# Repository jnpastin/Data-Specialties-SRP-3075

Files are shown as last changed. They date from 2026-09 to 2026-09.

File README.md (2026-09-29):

# Data Specialties SRP-3075

This repository documents the electrical design of a Data Specialties SRP-3075SD paper tape reader/punch through independently recreated KiCad schematics.

The schematics were produced by reverse engineering an original device. They are not original Data Specialties drawings.

## About the SRP-3075

The Data Specialties SRP-3075 is a tabletop, eight-channel paper tape reader and punch system introduced during the 1970s. It combines an optical tape reader and a tape punch in a single enclosure.

The standard SRP-3075 used separate DTL/TTL-compatible parallel interfaces for the reader and punch. The SRP-3075SD added an RS-232 serial interface for both functions and included data buffering to accommodate the difference between the incoming serial data rate and the mechanical speed of the punch.  The "SD" model designation described in the manual was not present on the sample device, it was designated solely as SRP-3075 or ST1 on the badges affixed to the device.

The serial model supports:

- Paper tape punching at 300, 600, or 750 baud
- Paper tape reading at 300, 600, 750, 1200, 1500, 2400, or 3000 baud
- Eight data channels plus the sprocket channel
- Independent reader and punch control
- RS-232 data and handshake signals
- Remote reader and punch control using ASCII DC1 through DC4 characters
- Buffered punch data while the punch mechanism starts or is temporarily unavailable

The punch operates mechanically at up to 75 characters per second. The optical reader operates at up to 300 characters per second.  This aligns with the available serial baud rates.  Since the serial configuration is 8 data bits and 1 stop bit (8-N-1), each character is 10 bits long.

## Repository Purpose

The purpose of this repository is to preserve the electrical design of the SRP-3075SD and provide usable technical information for:

- Restoration and repair
- Circuit analysis and troubleshooting
- Historical preservation
- Replacement circuit development
- Study of late-1970s paper tape equipment

The available manufacturer technical manual describes installation, operation, interfaces, options, and system-level behavior, but does not contain the complete electrical schematics needed to understand or repair the electronics.

## Repository Contents

Each major assembly directory contains some or all of the following:

- KiCad project files
- Hierarchical KiCad schematics
- Generated netlists
- PDF schematic exports
- Component-location images

The KiCad schematics and netlists are the editable engineering sources. PDF exports are provided for convenient viewing, while component-location images assist with identification and comparison against the physical hardware.  DSI did not silkscreen the boards on the sample unit.  Symbol references are the authors, except where noted in the schematics.

The repository does not currently contain recreated PCB layouts. Any placeholder KiCad PCB files should not be interpreted as representations of the original board routing.

## Source Documentation

The primary manufacturer reference used during this project was:

> Data Specialties Inc., *SP75 / SRP3075 "S" Series Technical Manual*, Specification No. 3601A, July 1978.

A scanned copy is available here and through Bitsavers.

The manual documents the product variants, operating procedures, options, interface signals, timing, and system specifications. It does not include the complete board-level electrical schematics recreated in this repository.

## Reverse-Engineering Method

The schematics in this repository were recreated through examination of original hardware. The work included:

- Identifying components and assemblies
- Tracing printed circuit board connections
- Reconstructing connector pinouts
- Identifying power and signal relationships
- Analyzing circuit operation
- Comparing observed behavior with the manufacturer technical manual
- Creating hierarchical KiCad schematics and netlists

The system is implemented primarily with conventional TTL and CMOS logic, timers, comparators, discrete transistor circuits, and electromechanical drivers. It does not depend on programmable logic, firmware, ROM-based control, or undocumented microcode.

Because the behavior is represented directly by the circuitry, the electrical reverse engineering is considered substantially complete. Corrections may still be made as restoration and functional testing of the original device continue.

---

## System Architecture

The SRP-3075 consists of four major electrical assemblies represented in this repository.

### Serial Interface and Reader Control

The serial and reader-control board provides the external RS-232 interface and controls the optical tape reader.

Its major functions include:

- RS-232 transmit, receive, and handshake interfaces
- Serial-to-parallel conversion for received punch data
- Parallel-to-serial conversion for reader data
- Independent reader and punch baud-rate selection
- Baud-clock generation from a 5.0688 MHz crystal
- Recognition of remote-control characters
- Reader request and stepping control
- Reader data capture and transmission
- Tape-status processing
- Switched 24 V power for the reader motor
- Communication with the main logic and punch-control board

See [Serial Interface and Reader Control](./SRP3075_Serial-Reader_Control/README.md)

### Main Logic and Punch Control

The main logic and punch-control board coordinates punch operation and provides the electrical interface to the punch mechanism, front panel, serial board, motors, sensors, and optional parallel interface.

Its major functions include:

- Punch command and readiness logic
- Received-data buffering
- A 128-character punch FIFO
- Punch data registers
- Punch-cycle sequencing
- Punch-solenoid relay drivers
- Sprocket-punch control
- Punch stepper-motor drive
- AC punch-motor control
- Motor speed detection and synchronization
- Feed control
- Front-panel switch and indicator logic
- Tape-low and tape-error handling
- Power-on reset and system-ready generation
- Interconnection with the serial and reader-control board

See [Main Logic and Punch Control](./SRP3075_Main_Logic-Punch_Control/README.md)

### Optical Tape Reader

The reader assembly is a Decitek 261E7010 optical paper tape reader. It detects the eight data channels and sprocket channel and advances the tape using a stepper-driven transport.

The documented reader electronics include:

- Optical sensing for eight data channels
- Optical sprocket-hole sensing
- Signal conditioning for the optical sensors
- Stepper-motor drive circuitry
- Reader motor and transport connections
- Reader power-supply circuitry
- Interface connections to the serial and reader-control board

See [Decitek Optical Tape Reader](./Decitek_261E7010_Tape_Reader/README.md)

### Power Supply

The power-supply assembly provides the voltage rails used by the logic, serial interface, analog circuitry, motors, and electromechanical drivers.

The documented supply includes:

- +5 V logic supply
- +12 V supply
- -12 V supply
- +24 V control and motor supply
- Rectification, filtering, regulation, and protection
- AC input and transformer connections
- Ground and chassis relationships
- Connections to the other system assemblies

See [Power Supply](./SRP3075_PowerSupply/README.md)

## Data Flow

### Punch Path

Serial data enters through the RS-232 interface on the serial and reader-control board. The serial controller converts each received character into parallel data and passes it to the main logic board.

The main logic board stores the received characters in the punch FIFO. This allows data reception to continue while the punch motor starts and accommodates temporary differences between the serial input rate and the mechanical punch rate.

Characters are transferred from the FIFO into the punch registers and presented to the relay-driver channels. The punch sequencer coordinates the data punches, sprocket punch, tape advance, and mechanical synchronization required for each character.

### Reader Path

The reader-control logic requests a tape step and the reader advances the tape by one character position. The optical reader then presents the eight data-channel states and the sprocket indication to the serial board.

The serial controller loads the reader data and transmits the corresponding serial character through the RS-232 interface. Reader operation is controlled by the front-panel switch, remote-control logic, and the RS-232 Request to Send and Clear to Send signals.

## Remote Control

When remote control is enabled, the serial interface recognizes the ASCII device-control characters DC1 through DC4:

| Character | Function |
|---|---|
| DC1 | Start reader |
| DC2 | Start punch |
| DC3 | Stop reader |
| DC4 | Stop punch |

When remote control is disabled, these characters are handled as ordinary received data and may be punched.

---

## Accuracy and Limitations

The schematics are intended to represent the examined hardware as accurately as possible. Signal names have been assigned or normalized where necessary to make the reconstructed design understandable and maintainable.

Although the reverse engineering is substantially complete, errors remain possible. Restoration, measurement, and functional testing may identify:

- Incorrectly traced connections
- Incorrect component values
- Differences between production revisions
- Undocumented factory modifications
- Repairs or modifications made during the life of the examined device

Any such findings will be incorporated into the schematic set as they are verified.

These materials should not be treated as original manufacturer service documentation. Exercise appropriate care when working with the equipment, particularly around AC line voltage, high-current supplies, motors, and electromechanical assemblies.

## Contributions

Corrections and additional information are welcome, particularly:

- Photographs of other SRP-3075 or SP75 units
- Board-revision information
- Component substitutions
- Original service documentation
- Factory schematic packages
- Verified differences between machine configurations
- Restoration and repair findings

Please include supporting observations, measurements, photographs, or documentation when proposing technical corrections.

## License

This repository is licensed under the terms provided in LICENSE.

Manufacturer names, model numbers, and trademarks are used for identification and historical documentation.

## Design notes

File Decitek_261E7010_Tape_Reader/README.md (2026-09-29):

# Decitek 261E7010 Optical Tape Reader

## Overview

This directory contains reverse-engineered schematics and supporting material for the Decitek 261E7010 optical paper tape reader used in the Data Specialties SRP-3075.

The 261E7010 was a third-party OEM reader module incorporated into the SRP-3075. It provides the optical sensing, signal conditioning, and electromechanical transport needed to read eight-channel, one-inch paper tape.

The schematics were recreated through examination of the reader installed in an original SRP-3075. They are not original Decitek or Data Specialties drawings.

## Function within the SRP-3075

The reader forms the input side of the SRP-3075 reader/punch system. It performs three primary functions:

- Detects the eight data channels and sprocket channel
- Conditions the optical sensor outputs into logic-level signals
- Advances the tape one character position when commanded

The reader connects to the [Serial Interface and Reader Control](../SRP3075_Serial-Reader_Control/README.md), which provides reader sequencing, serial conversion, baud-rate generation, and switching of the reader module’s 24V supply.

The reader module does not perform serial conversion or interpret character values.

## Physical Construction

The reader consists of three main functional sections:

- Optical read station
- Signal-conditioning electronics
- Stepper-driven tape transport

Tape passes through a fixed optical read station containing eight data-channel sensors and one sprocket-channel sensor. A single motor drives the feed mechanism and sprocket through a belt.

The reader is designed as a self-contained OEM module with direction and data-polarity capabilities that are not fully exposed by the SRP-3075.

## Optical Read Station

The read station contains nine optical sensing channels:

- Data Channel 1
- Data Channel 2
- Data Channel 3
- Data Channel 4
- Data Channel 5
- Data Channel 6
- Data Channel 7
- Data Channel 8
- Sprocket Channel

The sensors have been identified as photoresistive devices based on observed behavior. Their exact manufacturer and part numbers have not been identified.

Each sensor changes resistance according to the amount of light passing through its corresponding tape position. The resulting signals are processed by the reader’s analog conditioning circuitry.

The sprocket channel identifies the feed hole associated with each character position. It provides the alignment indication needed to determine when the eight data-channel outputs represent valid character data.

## Signal Conditioning

The photoresistor outputs are converted into logic-level signals by circuitry within the reader assembly.

The signal-conditioning circuitry provides:

- Sensor biasing
- Threshold detection
- Logic-level conversion
- Individual outputs for the eight data channels
- A separate sprocket-channel output

The resulting signals are passed to the Serial Interface and Reader Control board for capture and serial transmission.

## Tape Transport

Tape movement is provided by a single variable-reluctance stepper motor.

The motor drives both the tape-feed mechanism and the sprocket through a belt. The transport advances the tape in discrete character-position increments under the control of the reader electronics.

The reader operates in a read-then-step sequence. Character data is observed while the tape is stationary, after which the transport advances the next character position into alignment with the read station.

## Power and Stepping Control

The reader assembly contains the stepper-motor drive circuitry. The Serial Interface and Reader Control board does not switch individual motor phases directly.

The serial board controls reader operation by switching the +24 V power supplied to the reader module. Its reader timing circuitry also provides the request or stepping control used by the module to advance the tape.

The switched supply is identified as `+24V_SW` in the reconstructed schematics.

## Direction Control

The Decitek reader supports bidirectional tape movement.

A direction-control input selects the direction in which the stepper-drive circuitry advances the transport. This reflects the reader’s design as a general-purpose OEM module rather than a subsystem developed specifically for the SRP-3075.

The SRP-3075 does not expose this capability. The direction input has no signal connected on the Serial Interface and Reader Control board, leveraging the internal pull-up which forces the reader to operate in a single direction.

Direction is therefore not selectable by the operator, the host system, or the SRP-3075 control logic.

## Data Polarity

The reader supports selectable output polarity.

A polarity-control input determines the logical interpretation of a detected hole. The module can represent a hole as either:

- Logical one, or mark
- Logical zero, or space

The SRP-3075 does not expose this selection. The polarity input has no signla connected on the Serial Interface and Reader Control board, relying on the internal pull-up, so that a hole is always reported as a logical one, or mark.

Polarity is therefore not configurable by the operator or host system.

## Interface

The reader connects to the Serial Interface and Reader Control board through a 20-position connector.

The interface includes the following categories of connections:

### Power

- Switched +24 V reader supply
- Reader logic and sensing supplies
- Ground connections

### Control Inputs

- Tape-step or reader-request control
- Direction selection
- Hole-polarity selection

### Sensor Outputs

- Reader Channel 1
- Reader Channel 2
- Reader Channel 3
- Reader Channel 4
- Reader Channel 5
- Reader Channel 6
- Reader Channel 7
- Reader Channel 8
- Reader Sprocket

The direction and polarity inputs are fixed by wiring on the Serial Interface and Reader Control board. They are functional capabilities of the reader module but are not variable during normal SRP-3075 operation.

## Repository Contents

This directory contains:

- KiCad project files
- Hierarchical KiCad schematics
- A generated netlist
- A PDF schematic export
- A component-location image

The KiCad schematics and netlist are the editable engineering sources. The PDF is provided for convenient viewing, and the component-location image assists with locating parts on the original assembly.

The repository does not contain a recreated PCB layout. Any placeholder KiCad PCB file should not be interpreted as representing the original board routing.

## Schematic Organization

The reconstructed design is divided into functional sheets covering:

- Optical sensing and signal conditioning
- Tape-reader motor drive
- Reader power supply and distribution

This organization is intended to make the operation of the circuit easier to understand. It does not necessarily reflect the organization of any original Decitek documentation.

## Reverse-Engineering Notes

The schematics were recreated by identifying components, tracing PCB connections, analyzing circuit operation, and comparing the assembly’s behavior with the available Data Specialties documentation.

The examined board includes complete component reference designators, but Decitek used an unconventional scheme for the integrated circuits. Each IC is identified by a single letter rather than a conventional `U`-prefixed number.

KiCad requires the reference to contain a numeric portion, so `_1` is appended to each original IC designation in the reconstructed schematics. Unit letters then identify individual gates or sections within the device. For example, `F_1B` identifies unit B of the IC marked `F` on the original assembly. The suffix does not imply the existence of an `F_2` device.

The reverse engineering of the assembly is considered substantially complete. No programmable logic, firmware, ROM-based control, or other inaccessible logic is present.

## Accuracy and Open Questions

The schematics are believed to accurately represent the examined assembly. Corrections may still be made as restoration and functional testing continue.

Remaining identification questions include:

- Exact photoresistor manufacturer and part number
- Exact specifications of the optical illumination components
- Differences between Decitek production revisions
- Differences between this module and modules installed in other equipment

No significant functional uncertainties are presently known.

## Safety

The reader contains moving mechanical components and motor-drive circuitry. Disconnect power before servicing the assembly or working near the tape transport.

Exercise care when testing the reader outside the complete SRP-3075 because the module depends on externally supplied power and control connections.

## License

This material is licensed under the [terms provided in the repository](../LICENSE).

Manufacturer names, model numbers, and trademarks are used only for identification and historical documentation.

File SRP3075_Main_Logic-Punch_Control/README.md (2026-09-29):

# SRP-3075 Main Logic and Punch Control

## Overview

This directory contains reverse-engineered schematics and supporting material for the Main Logic and Punch Control board used in the Data Specialties SRP-3075.

The Main Logic and Punch Control board is the central system board of the SRP-3075. It serves as the primary interconnection point for the machine's subsystems and is responsible for system coordination, punch data handling, punch control, front-panel operation, and parallel-interface functions.

The schematics were recreated through examination of an original SRP-3075. They are not original Data Specialties drawings.

## Function within the SRP-3075

Responsibility for machine operation is divided between this board and the Serial Interface and Reader Control board.

The Main Logic and Punch Control board is responsible for:

- System clock generation
- Power-on reset generation
- Front-panel controls and indicators
- Punch data buffering
- Punch sequencing
- Punch motor control
- Punch relay drive
- Punch stepper control
- Parallel-interface support
- System-level coordination
- Interconnection of the machine's assemblies

The Serial Interface and Reader Control board provides serial communications and reader-control functions, while this board provides the core machine-control functions required to operate the punch mechanism.

## System Architecture

The Main Logic and Punch Control board serves as the connectivity hub for the SRP-3075.

Major connections include:

- Serial Interface and Reader Control board
- Punch mechanism
- Front panel
- Power supply
- AC motor sensor
- Stepper motor
- Optional parallel-interface circuitry
- Optional low tape detection module (Option G)

Most machine control signals pass through this board.

## Data Flow

The punch datapath is shown below.

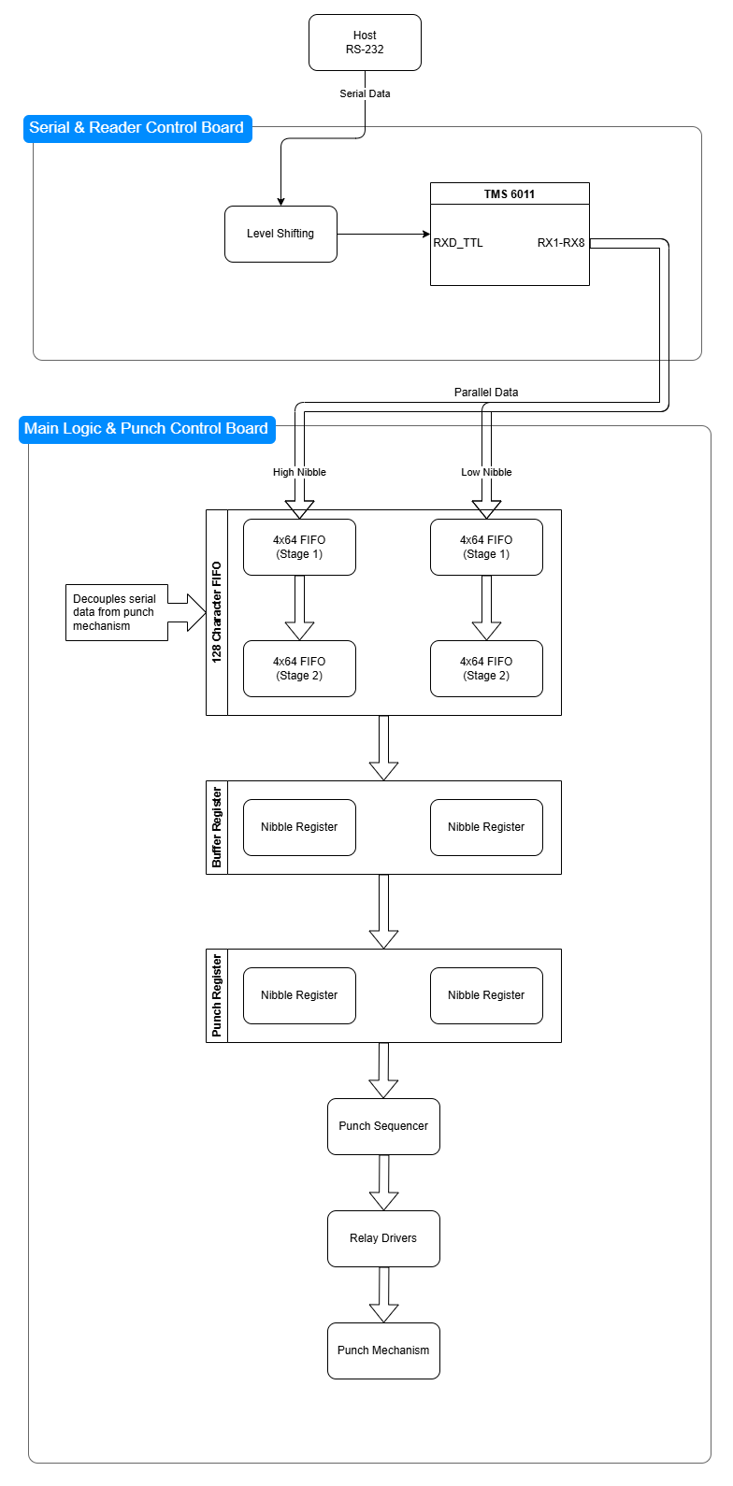
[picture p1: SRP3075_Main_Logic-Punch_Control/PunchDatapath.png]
Punch Datapath Flowchart


A received character passes through several stages before it reaches the punch mechanism:

1. The Serial Interface and Reader Control board converts incoming serial data into parallel character data.
2. The character enters the FIFO buffer.
3. The FIFO transfers the next available character into the Buffer Register.
4. The Buffer Register transfers the character into the Punch Register.
5. The Punch Sequencer coordinates the punch cycle.
6. Relay-driver circuitry energizes the appropriate punch channels.
7. The punch mechanism produces the corresponding tape pattern.

This staged approach allows serial reception, FIFO buffering, punch preparation, and mechanical punching to operate largely independently.

## FIFO Buffer

Received punch data is stored in a 128-character FIFO buffer.

The FIFO is implemented using four 3341 FIFO devices arranged as two cascaded paths:

- High nibble path
- Low nibble path

Each path uses two 64×4 FIFO devices connected in cascade, providing a total storage capacity of 128 punch characters.

The FIFO allows the machine to continue accepting serial data while the punch mechanism is operating or starting.

### FIFO Device Notes

The FIFO implementation uses Signetics 3341 PMOS FIFO memories.

Unlike later TTL memory devices, the 3341 requires:

- +5 V
- GND
- -12 V

This multi-supply requirement was not unusual for memory devices of the period.

Anyone investigating replacements should verify power-supply requirements carefully. Devices with similar functionality may not be electrically compatible even if they appear mechanically compatible.

## Buffer and Punch Registers

Two layers of registers exist between the FIFO and the punch mechanism:

### Buffer Register

The Buffer Register receives the next character from the FIFO and isolates FIFO timing from punch timing.

### Punch Register

The Punch Register contains the character currently being punched.

The punch-control logic operates from the Punch Register outputs rather than directly from FIFO data.

This separation allows the machine to prepare the next character while the current character is being processed.

## System Coordination

Several core machine functions originate on this board.

### System Clock

The main machine timing reference is generated on the Main Logic and Punch Control board and distributed to the remaining circuitry.

### Power-On Reset

The board generates the power-on initialization sequence that establishes a known machine state after power is applied.

### System Ready

Reset and timing circuitry produce the signals that indicate when normal machine operation may begin.

## Punch Control

Punch operation is coordinated by several dedicated subsystems.

### Punch Sequencer

The sequencer controls the order and timing of punch operations.

Responsibilities include:

- Character punching
- Sprocket punching
- Tape advance timing
- Coordination with motor synchronization circuitry

### AC Motor Synchronization

The punch mechanism contains an AC motor with a position sensor.

Synchronization circuitry monitors motor position and derives timing signals used by the punch-control logic.

The design includes:

- Sensor conditioning
- Missing-pulse detection
- Motor-speed monitoring
- Punch timing synchronization

### Stepper Drive

Dedicated circuitry controls tape advancement and punch positioning through the punch stepper subsystem.

### Relay Drivers

Relay-driver circuitry converts logic-level punch data into the power levels required by the punch mechanism.

Individual relay channels correspond to:

- Punch channels 1 through 8
- Sprocket channel (Relay/Punch 9)

## Front Panel Interface

The Main Logic and Punch Control board interfaces directly with the machine's controls and indicators.

Functions include:

- Reader control
- Punch control
- Remote-control enable
- Status indication
- Power indication

This board therefore forms the primary interface between the operator and the machine.

## Parallel-Interface Support

Evidence suggests that the Main Logic and Punch Control board was designed for use across multiple SRP-3075 variants.

The examined board contains populated circuitry associated with a parallel punch interface.

In the serial configuration this functionality is disabled by the `/SERIAL_DETECT` signal supplied by the Serial Interface and Reader Control board.

The corresponding reader-side parallel-interface circuitry is not populated on the examined board. An unpopulated DIP-14 footprint is present in this area.

These observations suggest that Data Specialties likely used a common logic board across multiple SRP-3075 configurations, with variant-specific functionality provided through different companion interface boards and selective component population.

This conclusion is based on observed hardware and should be considered an informed reconstruction rather than documented manufacturer information.

## Connectors

This board acts as the primary interconnection point for the system.

Connectors include:

- Power-supply interface
- Serial-board interface
- Front-panel interface
- Stepper-motor interface
- AC motor sensor interface
- Relay outputs
- Parallel-interface connections

The board distributes power, timing, status, and control signals among the machine's assemblies.

## Component Reference Designators

The original Main Logic and Punch Control board contained no component reference designators.

All component references shown in the reconstructed schematics were assigned during reverse engineering.

These assigned references are used consistently throughout:

- Schematics
- Netlists
- Component-location documentation
- Restoration notes

They are not original manufacturer designations.

## Repository Contents

This directory contains:

- KiCad project files
- Hierarchical KiCad schematics
- Generated netlists
- PDF schematic exports
- Component-location images

The KiCad schematics and netlists are the editable engineering sources.

The repository does not currently contain recreated PCB layouts. Any placeholder PCB files should not be interpreted as representations of the original board routing.

## Reverse-Engineering Notes

The schematics were recreated by:

- Component identification
- PCB tracing
- Connector reconstruction
- Signal tracing
- Functional analysis
- Comparison with available manufacturer documentation
- Cross-reference against the Serial Interface and Reader Control board and Power Supply schematics

Signal names were assigned or normalized where necessary to make the design understandable and maintainable.

The reverse engineering of this assembly is considered substantially complete.

## Accuracy and Open Questions

The schematics are believed to accurately represent the examined hardware.

Corrections may still be incorporated as restoration and functional testing continue.

Areas that may benefit from additional investigation include:

- Differences between production revisions
- Alternative interface-board configurations
- Factory-installed options
- Undocumented hardware modifications
 
No significant functional uncertainties are presently known.
 
## Safety
 
This board contains connections to:
 
- AC motor-control circuitry
- Relay-driver circuitry
- +24 V power circuitry
- External electromechanical assemblies
 
Disconnect power before servicing the machine and verify proper connector placement before reconnecting associated assemblies.
 
## License
 
This material is licensed under the terms provided in the ../LICENSE.
 
Manufacturer names, model numbers, and trademarks are used only for identification and historical documentation.

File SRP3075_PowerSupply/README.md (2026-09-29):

# SRP-3075 Power Supply

## Overview

This directory contains reverse-engineered schematics and supporting material for the power-supply assembly used in the Data Specialties SRP-3075.

The power supply provides the DC rails required by the logic boards, serial interface, optical tape reader, punch-control circuitry, and electromechanical assemblies.

The schematics were recreated through examination of the power supply in an original SRP-3075. They are not original Data Specialties drawings.

## Function within the SRP-3075

The power-supply assembly converts incoming AC power into the DC supplies used throughout the device.

The documented outputs include:

- +5V for digital logic
- +12V for analog and interface circuitry
- -12V for analog and serial-interface circuitry
- +24V for motors, relays, solenoids, and other electromechanical loads
- Logic ground, identified as `GND`
- 24V power return, identified as `GND_24V`

The supply connects primarily to the [Main Logic & Punch Control](../SRP3075_Main_Logic-Punch_Control/README.md) board, which distributes power to the remaining assemblies.

## Power-Supply Architecture

The reconstructed design is divided into three functional sections:

- +5V rail
- +12V and -12V rails
- +24V rail

The positive regulated supplies use external pass transistors to provide additional output-current capability:

- The +5V rail uses one external pass transistor.
- The +12V rail uses one external pass transistor.
- The +24V rail uses two external pass transistors.
- The -12V rail does not use an external pass-transistor stage.

The schematics preserve the distinction between logic ground and the higher-current 24V return where that distinction is present in the original design.

## +5V Rail

The +5V rail supplies the TTL and CMOS logic used throughout the SRP-3075.

The circuit includes:

- Transformer input
- Rectification
- Bulk filtering
- Voltage regulation
- One external pass transistor
- Current-limiting and protection circuitry
- Output filtering

The regulator controls the external pass transistor, which provides the output-current capability required by the machine's digital logic.

## +12V and -12V Rails

The +12V and -12V rails supply analog, timing, sensing, and RS-232 interface circuitry.

These rails are used by circuitry including:

- RS-232 line interfaces
- Operational amplifiers and comparators
- Analog sensing circuits
- Timing and threshold circuits

The +12V rail uses a regulator with one external pass transistor to provide additional output-current capability.

The -12V rail is implemented separately and does not use an external pass-transistor stage.

## +24V Rail

The +24V rail supplies the higher-power electromechanical portions of the machine.

Loads associated with this rail include:

- Punch relay and solenoid drivers
- Punch stepper circuitry
- Reader module power
- Other 24V electromechanical loads

The +24V regulator controls two external pass transistors to provide the required output-current capability.

The design uses a separate return identified as `GND_24V` for the higher-current 24V load path. The relationship between `GND` and `GND_24V` should be preserved when servicing or reconnecting the assembly.  

## Main Logic Board Connector

The power supply connects to the Main Logic and Punch Control board through a multi-position wiring connector.

During reverse engineering, the connector wiring in the examined device was found not to agree with the corresponding connections on the main logic board. The `GND` and `GND_24V` positions were reversed.

This discrepancy was corrected during restoration by repinning the connector.

The connector shown on the root sheet of the reconstructed schematic represents the corrected configuration, not the as-found wiring. A note on the root sheet documents:

- The original as-found discrepancy
- The corrected `GND` and `GND_24V` positions
- The specialized extraction tool required to remove and reposition the connector contacts

Anyone comparing the schematic against an unrestored device should review this note before altering the connector.

Do not assume that another SRP-3075 has already received the same correction. Verify its wiring against the board connections before applying power.

## Grounding

The schematics distinguish among:

- `GND`, used as the logic and low-power circuit reference
- `GND_24V`, used as the return for higher-current 24V loads
- Chassis or protective earth

These connections serve different functions within the reconstructed design and should not be treated as interchangeable connector positions.

`GND` and `GND_24V` are intentionally routed separately throughout the system and are connected together only at the negative terminal of C3 on the power-supply assembly. This single-point connection limits interaction between high-current, high noise 24V return paths and the logic ground system. The connector correction preserves the intended return-current paths for each ground network.

## Component Reference Designators

The original power-supply assembly was only partially annotated. Approximately half of its components carried Data Specialties reference designators, while the remaining components had no visible references.

Original Data Specialties references are preserved unchanged in the reconstructed schematics.

For components without an original reference, an `X` is inserted into the designator to identify the reference as one assigned during reverse engineering.

Examples:

- `C12` is capacitor 12 as designated by Data Specialties.
- `CX7` is the seventh otherwise-unreferenced capacitor assigned during schematic reconstruction.
- `R19` is an original Data Specialties resistor reference.
- `RX7` is an author-assigned reference for an otherwise-unreferenced resistor.

The original and assigned reference sequences are independent. An `X`-marked reference does not imply that a corresponding original reference exists.

This convention preserves the available manufacturer markings while providing every component with a unique identifier for analysis, documentation, and repair.

## Repository Contents

This directory contains:

- KiCad project files
- Hierarchical KiCad schematics
- A generated netlist
- A PDF schematic export
- A component-location image

The KiCad schematics and netlist are the editable engineering sources. The PDF is provided for convenient viewing, and the component-location image assists with locating parts on the physical assembly.

The repository does not contain a recreated PCB layout. Any placeholder KiCad PCB file should not be interpreted as representing the original board routing.

## Schematic Organization

The reconstructed design is divided into functional sheets covering:

- +5V generation and regulation
- +12V generation and regulation
- +24V generation and regulation
- Transformer, AC connections, output connectors, power distribution, and -12V generation and regulation.

The root sheet provides the overall interconnection among the rail circuits, transformer windings, wiring, and output connectors.

Important restoration notes, including the corrected `GND` and `GND_24V` connector positions, are recorded on the root sheet.

## Reverse-Engineering Notes

The schematics were recreated by:

- Identifying components and their values
- Recording available board reference designators
- Assigning references to unmarked components
- Tracing PCB connections
- Tracing chassis and point-to-point wiring
- Reconstructing connector pinouts
- Analyzing regulation and power-distribution circuits
- Comparing power connections against the other SRP-3075 assemblies

Rail and connector names were assigned or normalized where necessary to make the reconstructed design understandable and maintainable.

The reverse engineering of the assembly is considered substantially complete. Corrections may still be made as restoration, measurement, and functional testing continue.

## Accuracy and Restoration Status

The schematics are believed to accurately represent the restored assembly.

The main logic board connector is intentionally drawn in its corrected configuration. It does not reproduce the reversed `GND` and `GND_24V` wiring found during disassembly.

Possible remaining areas for investigation include:

- Differences between production revisions
- Differences among input-voltage configurations
- Undocumented factory changes
- Prior repairs or field modifications
- Exact identification of components whose markings are incomplete

No significant functional uncertainties are presently known.

## Safety

This assembly contains hazardous AC line voltage, high-current DC supplies, large capacitors, and exposed power components.

Before servicing the power supply:

- Disconnect the device from AC power.
- Allow capacitors to discharge.
- Verify stored voltages with appropriate test equipment.
- Confirm the transformer and line-voltage configuration.
- Verify connector wiring before reconnecting any assembly.
- Observe correct polarity when replacing polarized capacitors.
- Preserve protective-earth and chassis connections.

The +24V supply can deliver sufficient current to damage wiring, connectors, circuit boards, and electromechanical components if incorrectly connected.

The connector-repinning information on the schematic documents a verified restoration correction. It is not a substitute for checking the wiring and board connections in another device.

## License

This material is licensed under the ../LICENSE.

Manufacturer names, model numbers, and trademarks are used only for identification and historical documentation.

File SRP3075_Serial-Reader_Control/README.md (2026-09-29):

# SRP-3075 Serial Interface and Reader Control

## Overview

This directory contains reverse-engineered schematics and supporting material for the Serial Interface and Reader Control board used in the Data Specialties SRP-3075.

The board provides two primary functions:

- Serial communications
- Reader control and timing

It implements the RS-232 interface used by the serial (SD) model and controls operation of the optical tape reader. It also exchanges punch data, reader and punch control signals, status information, and system timing signals with the Main Logic and Punch Control board.

The schematics were recreated through examination of the board installed in an original SRP-3075. They are not original Data Specialties drawings.

## Function within the SRP-3075

System responsibilities are divided between this board and the [Main Logic and Punch Control](../SRP3075_Main_Logic-Punch_Control/README.md) board.

The Serial Interface and Reader Control board is responsible for:

- Serial communications with the host
- Reader control and timing
- Reader data capture and transmission
- Serial control-character detection and decoding

The Main Logic and Punch Control board provides system coordination, clock and reset generation, punch data processing and buffering, punch control, front-panel handling, parallel interface support, and the primary interconnection point for the machine’s assemblies.

## Serial Communications

The board provides the serial communications functions of the SRP-3075 serial model.

These functions consist of:

- Serial data transfer
- RS-232 configuration and flow control
- Control-character detection and decoding

The serial interface transports data in both directions:

- Data received from the host is converted from serial data into an eight-bit parallel character and passed to the Main Logic and Punch Control board for processing and punching.
- Data obtained from the optical reader is converted from an eight-bit parallel character into serial data and transmitted to the host.

The interface uses 8N1 framing, with one start bit, eight data bits, and one stop bit. Each character therefore occupies ten serial bit times.

## Serial Controller

A TMS6011NC asynchronous communications controller performs the serial-to-parallel and parallel-to-serial data conversion.

### Reader Transmit Path

The eight reader channels enter the TMS6011 on `TI1` through `TI8`.

The TMS6011 loads the reader character and converts it into the serial `TXD_TTL` output. The RS-232 line-interface circuitry then converts that logic-level signal into the voltage levels required by the host interface.

### Punch Receive Path

Serial data received from the host is converted to the logic-level `RXD_TTL` signal by the RS-232 line-interface circuitry.

The TMS6011 converts `RXD_TTL` into the parallel outputs `RXD1` through `RXD8`. These eight data signals cross the inter-board connector to the Main Logic and Punch Control board.

The Main Logic and Punch Control board then performs the punch data processing, buffering, sequencing, and mechanical control required to punch the received character.

## RS-232 Line Interface

The external RS-232 interface is implemented with analog circuitry rather than dedicated integrated RS-232 transceivers.

The line-interface circuitry converts between RS-232 voltage levels and the logic-level signals used by the TMS6011 and surrounding control logic.

The host interface provides:

- Transmitted Data
- Received Data
- Request to Send
- Clear to Send
- Data Terminal Ready
- Low Tape

The interface uses the board’s +12V and -12V supplies to generate and interpret the RS-232 signaling levels.

## Flow Control

The serial interface uses Clear to Send and Data Terminal Ready for flow control.

Clear to Send is provided by the host and controls whether the SRP-3075 may transmit reader data. Removing Clear to Send prevents further reader transmission until the host permits it to resume.

Data Terminal Ready is generated by the SRP-3075 and indicates whether the machine can accept serial data for punching. The host should suspend transmission when Data Terminal Ready is inactive and resume only after it becomes active again.

Request to Send is also used as part of reader selection and operation.

## Baud-Rate Generation and Selection

Reader and punch serial clocks are generated from a 5.0688 MHz crystal oscillator and associated rate-generation, counter, divider, and selection circuitry.

The clock signals supplied to the TMS6011 operate at sixteen times the selected serial baud rate.

The board provides separate baud-rate selections for reader transmission and punch reception.

### Punch Rates

The punch receive path supports:

- 300 baud
- 600 baud
- 750 baud

With ten serial bits per character, these rates correspond to:

- 30 characters per second
- 60 characters per second
- 75 characters per second

The maximum serial receive rate therefore corresponds to the punch mechanism’s maximum operating rate of 75 characters per second.

### Reader Rates

The reader transmit path supports:

- 300 baud
- 600 baud
- 750 baud
- 1200 baud
- 1500 baud
- 2400 baud
- 3000 baud

With ten serial bits per character, the maximum rate of 3000 baud corresponds to 300 characters per second, matching the maximum operating rate specified for the optical reader.

Reader and punch rates are selected using a DIP switch on the board.

## Control-Character Detection and Decoding

When the front-panel Remote Control function is enabled, the board recognizes four ASCII device-control characters:

| Character | Function |
|---|---|
| DC1 | Start reader |
| DC2 | Start punch |
| DC3 | Stop reader |
| DC4 | Stop punch |

The function-decoding circuitry detects these values in the received parallel character data and generates the appropriate reader or punch control request.

When Remote Control is enabled, recognized control characters are interpreted as commands rather than ordinary punch data.

When Remote Control is disabled, the characters are treated as ordinary received data and may be punched.

## Reader Control and Timing

The reader-control portion of the board operates the [Decitek optical tape reader](../Decitek_261E7010_Tape_Reader/README.md) module.

Its functions include:

- Reader start and stop control
- Reader-cycle timing
- Tape-step requests
- Detection of valid reader data
- Capture of the eight reader data channels
- Coordination with the serial transmit path
- Tape-low and tape-error processing (if Option G is installed, see [S Series Technical Manual](../DSI_S_Series_Technical_Manual.pdf))
- Switching the +24V supply delivered to the reader module

The Decitek reader performs the optical sensing, signal conditioning, stepper-motor drive, and mechanical tape transport. The serial board controls when the module is powered, when a tape step is requested, when reader data is captured, and when the resulting character is transmitted.

## Reader Power Switching

The board enables or disables the stepper motor on the reader module by switching the +24V supply delivered to it.

The switched supply is identified as `+24V_SW` in the reconstructed schematics.

The serial board does not drive the reader’s stepper-motor phases directly. Phase generation and motor-drive circuitry are contained within the Decitek reader assembly.

Switching the module’s +24V input is one mechanism used by the board to implement reader control. It is not a separate system-level responsibility.

## Reader Sequence

The board coordinates the reader’s read-then-step operating sequence.

A character is sensed while the tape is stationary. The eight reader channels are captured and presented to the TMS6011, which converts the parallel character into serial data for transmission.

The board then requests advancement to the next character position.

Timing circuitry coordinates the intervals required to:

- Initiate a reader cycle
- Capture valid channel data
- Load the serial transmitter
- Request a tape step
- Detect the sprocket indication
- Continue or terminate reader operation

Reader operation is coordinated with the serial transmit state, host flow control, local controls, remote-control commands, and tape-status signals (if installed).

## Reader Direction

The Decitek reader module supports bidirectional tape movement through a direction-control input.

The SRP-3075 does not expose this capability. The direction input is not connected on this board, leveraging the pull-up on the module which forces the reader to operate in one direction.

Direction is therefore not selectable through the serial interface, front-panel controls, or host commands.

## Reader Data Polarity

The Decitek reader supports selectable output polarity through a polarity-control input.

This board provides no signal on the hole polarity input to a fixed logic level so that the modeule's internal pull-up causes a detected hole to be represented as a logical one, or mark.

The alternate configuration, in which a hole represents a logical zero, or space, is not exposed by the SRP-3075.

## Inter-Board Interface

The board connects to the Main Logic and Punch Control board through a 36-position card-edge connector.

The inter-board interface carries:

- Parallel received data, `RXD1` through `RXD8`
- Reader and punch control signals
- Front-panel control states
- Tape-low and tape-error signals (if installed)
- System clock and reset signals
- Serial-board status and coordination signals
- +5V power
- Ground

Power for the serial board is supplied through this connector by the Main Logic and Punch Control board.

The Main Logic and Punch Control board is the primary connectivity hub for the machine. The serial board uses the card-edge connection to exchange the data, control, timing, status, and power connections required by the serial communications and reader-control subsystems.

## Major Board Connections

The major connections are:

- DB-25 connector for the RS-232 host interface
- 36-position card-edge connector to the Main Logic and Punch Control board
- 20-position card-edge connector to the Decitek optical reader

The 36-position card-edge connector carries both power and inter-board signals.

The 20-position card-edge reader connector carries the eight data channels, sprocket indication, control inputs, switched +24V power, +5V logic power, and ground connections required by the reader module.

## Component Reference Designators

The original Serial Interface and Reader Control board did not contain component reference designators.

All component reference designators shown in the reconstructed schematics were assigned during reverse engineering. They are not original Data Specialties designations.

The assigned references provide consistent identifiers for:

- Schematic organization
- Circuit analysis
- Component-location documentation
- Restoration and repair
- Cross-referencing among schematic sheets

The Main Logic and Punch Control board was also unreferenced. Its reconstructed schematics use the same author-assigned reference approach.

## Repository Contents

This directory contains:

- KiCad project files
- Hierarchical KiCad schematics
- A generated netlist
- A PDF schematic export
- A component-location image

The KiCad schematics and netlist are the editable engineering sources. The PDF is provided for convenient viewing, and the component-location image assists with locating parts on the physical board.

The repository does not contain a recreated PCB layout. Any placeholder KiCad PCB file should not be interpreted as representing the original board routing.

## Schematic Organization

The reconstructed design is divided into functional sheets covering:

- RS-232 line interface
- Read strobe and enable logic
- Receive handshake and shift logic
- Function decoding
- Reader drive timing
- +24V reader power switching
- Baud-rate generation
- Baud-rate selection
- Power distribution, bypassing, and unused logic sections

This organization reflects the functional structure of the reconstructed circuit. It does not necessarily reproduce the organization of any original Data Specialties engineering documentation.

## Reverse-Engineering Notes

The schematics were recreated by:

- Identifying components and values
- Assigning component reference designators
- Tracing PCB connections
- Reconstructing connector pinouts
- Following the serial receive and transmit paths
- Analyzing baud-rate generation and selection
- Tracing reader-control and timing circuits
- Identifying control-character detection and decoding
- Comparing the resulting design against the manufacturer technical manual
- Comparing inter-board signals against the Main Logic and Punch Control board and Decitek reader schematics

Signal names were assigned or normalized where necessary to make the reconstructed design understandable and maintainable.

The reverse engineering of the board is considered substantially complete. No programmable logic, firmware, ROM-based control, or inaccessible control logic is present.

## Accuracy and Open Questions

The schematics are believed to accurately represent the examined board. Corrections may still be made as restoration, measurement, and functional testing continue.

Possible remaining areas for investigation include:

- Differences between production revisions
- Undocumented factory modifications
- Prior repairs or field modifications
- Exact identification of components with incomplete markings

No significant functional uncertainties are presently known.

## Safety

The board uses +5 V, +12 V, -12 V, and +24V supplies and switches the +24V input to the reader module.

Before servicing:

- Disconnect the machine from AC power.
- Verify that supply voltages have discharged.
- Confirm connector orientation before reconnecting the board.
- Avoid connecting RS-232 signals directly to TTL-level circuitry.
- Verify reader power and ground connections before testing the reader outside the complete machine.
- Keep clear of the reader transport when switched power is applied.

## License

This material is licensed under the terms provided in the ../LICENSE.

Manufacturer names, model numbers, and trademarks are used only for identification and historical documentation.

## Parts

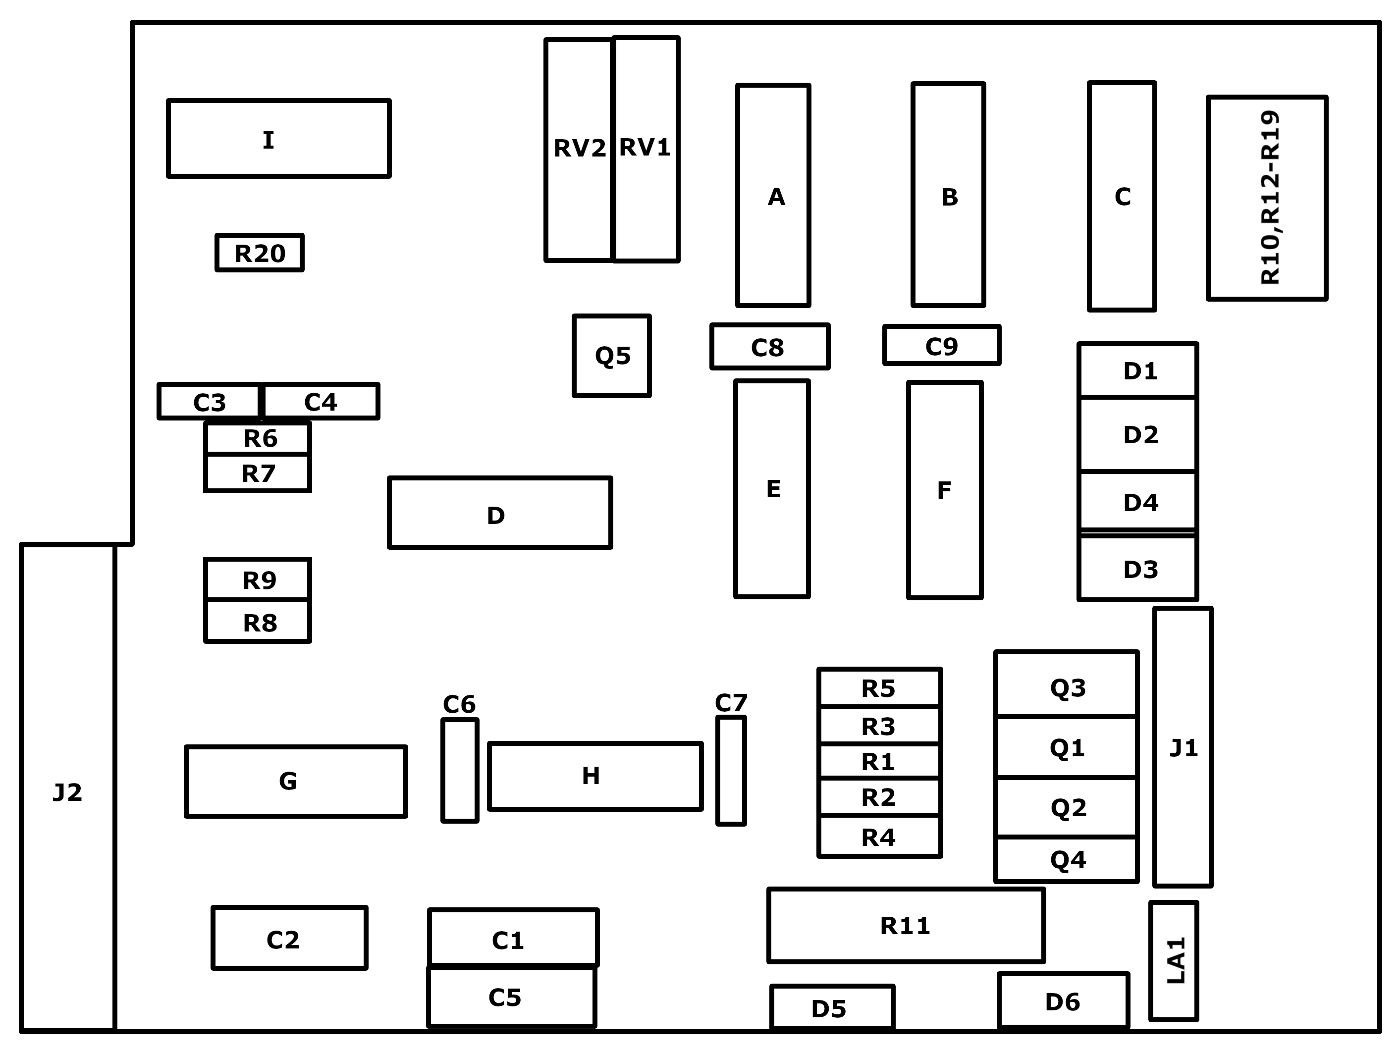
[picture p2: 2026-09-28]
Decitek_261E7010_Tape_Reader/ComponentLocations.png

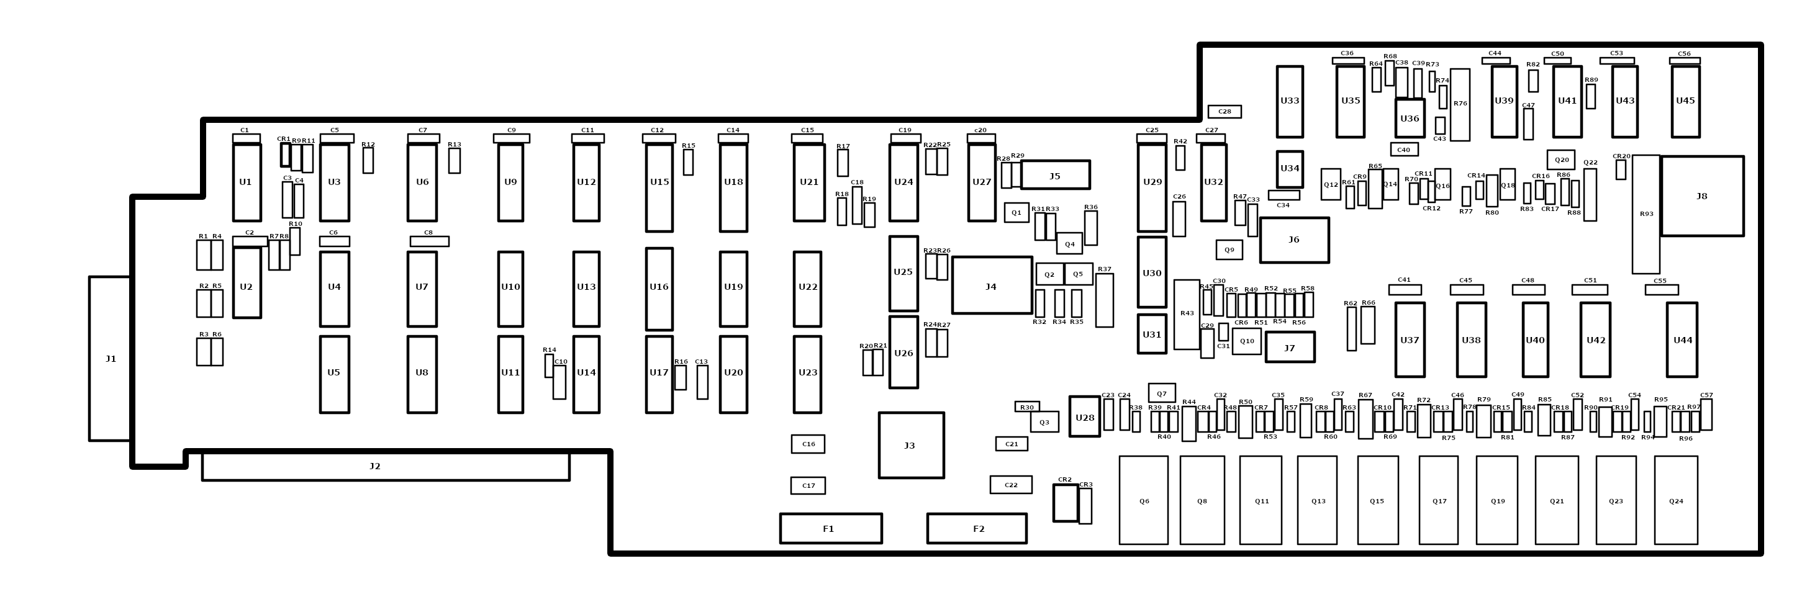
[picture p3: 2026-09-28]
SRP3075_Main_Logic-Punch_Control/ComponentLocations.png

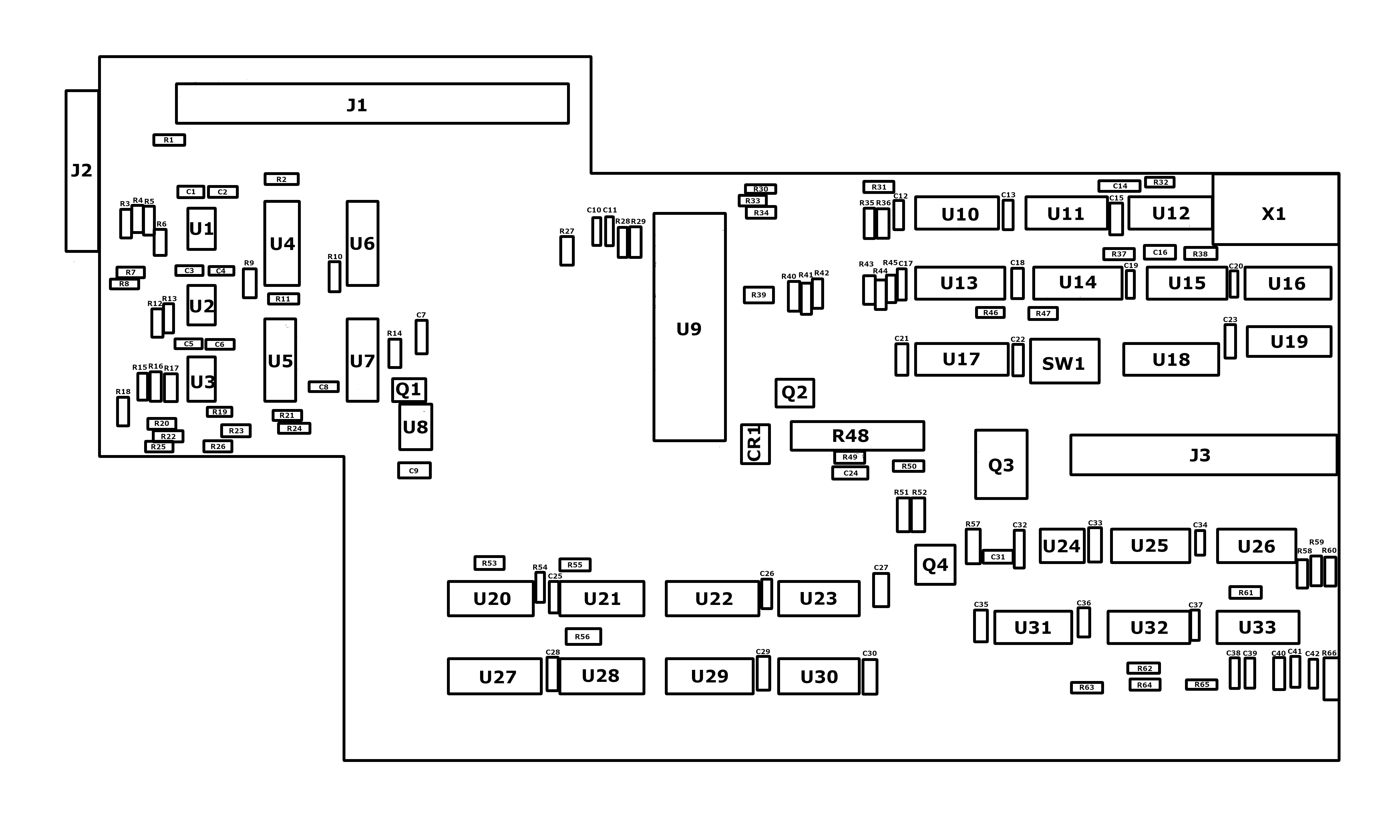
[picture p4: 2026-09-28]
SRP3075_Serial-Reader_Control/ComponentLocations.png

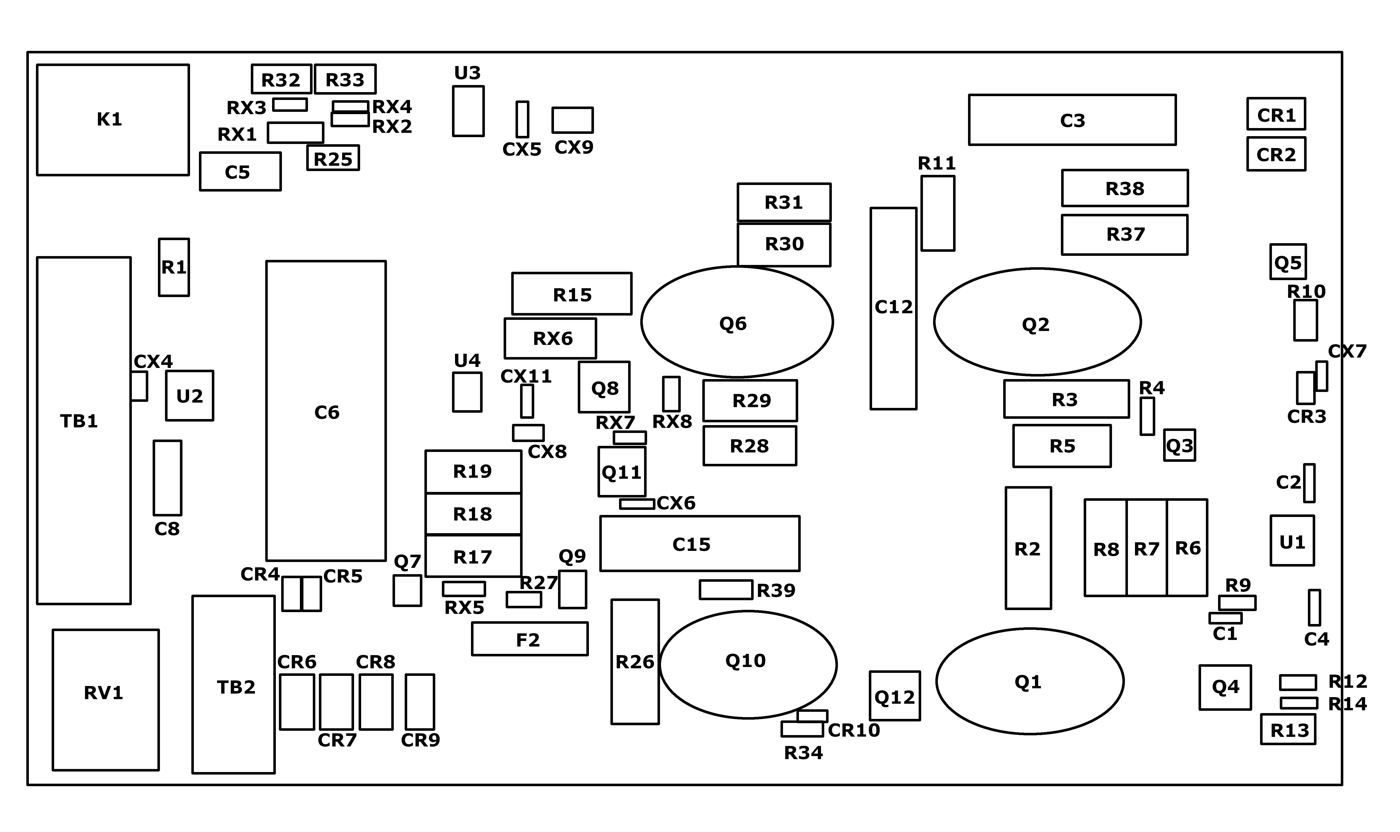
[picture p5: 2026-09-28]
SRP3075_PowerSupply/ComponentLocations.png

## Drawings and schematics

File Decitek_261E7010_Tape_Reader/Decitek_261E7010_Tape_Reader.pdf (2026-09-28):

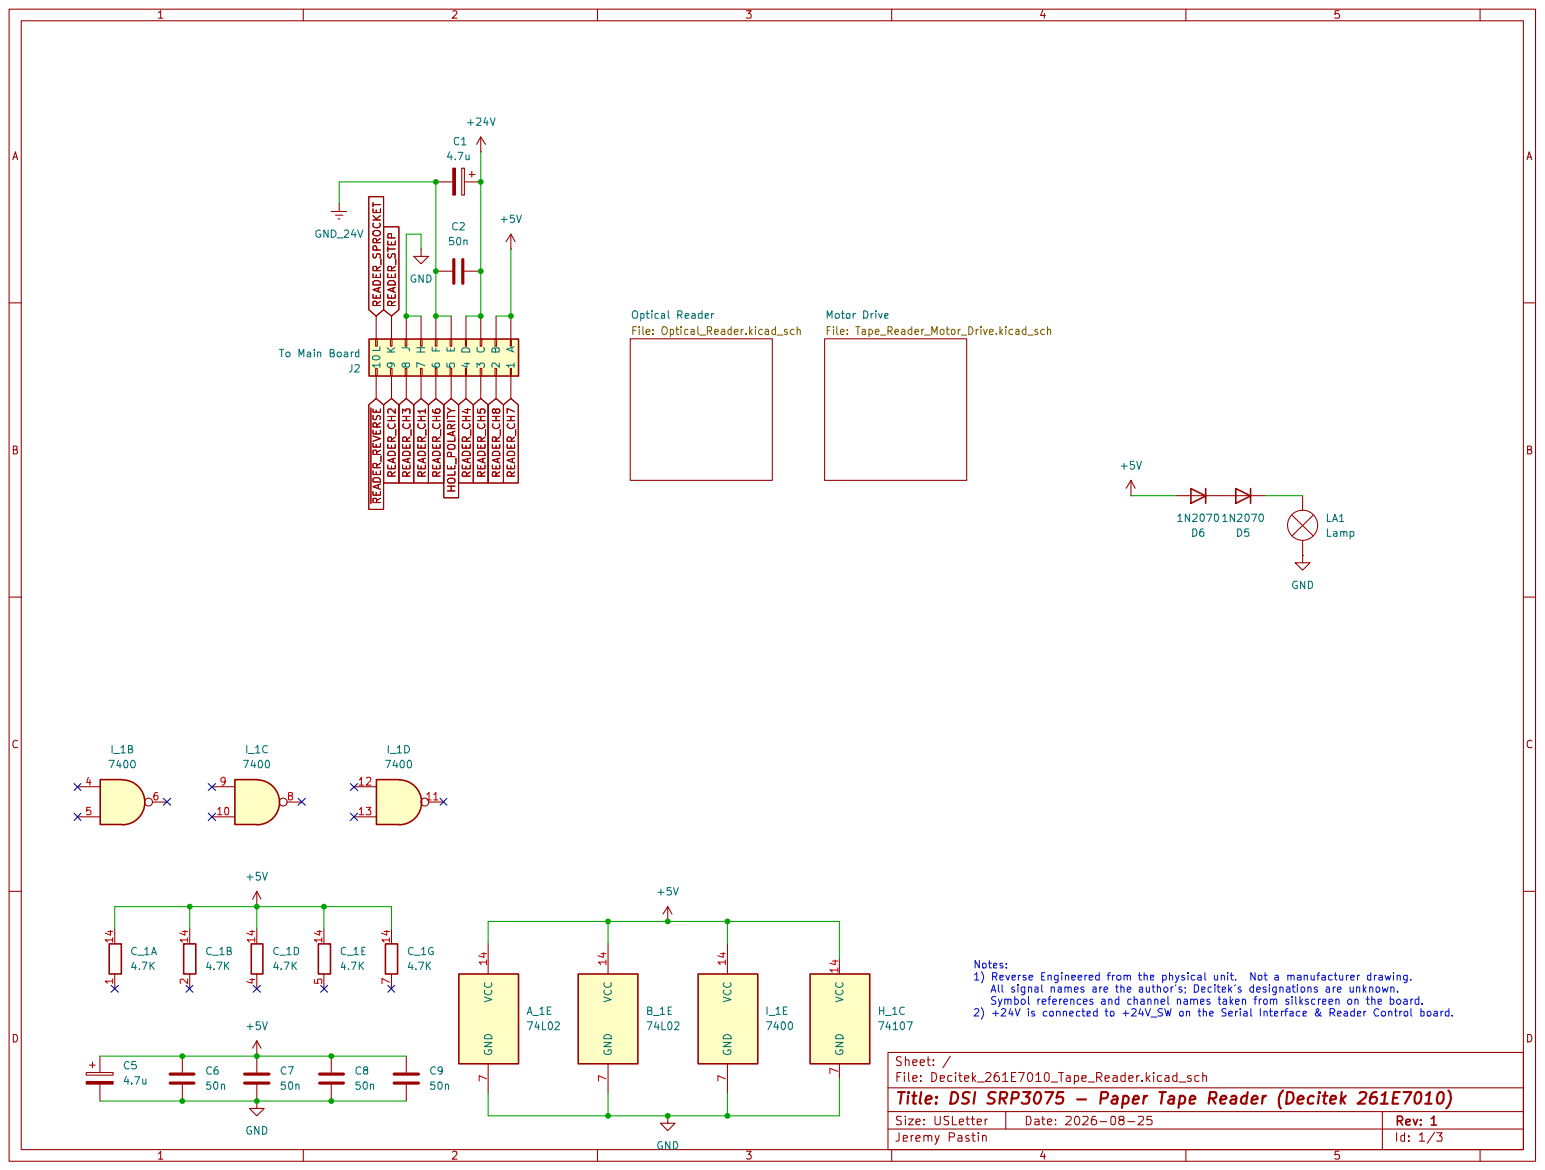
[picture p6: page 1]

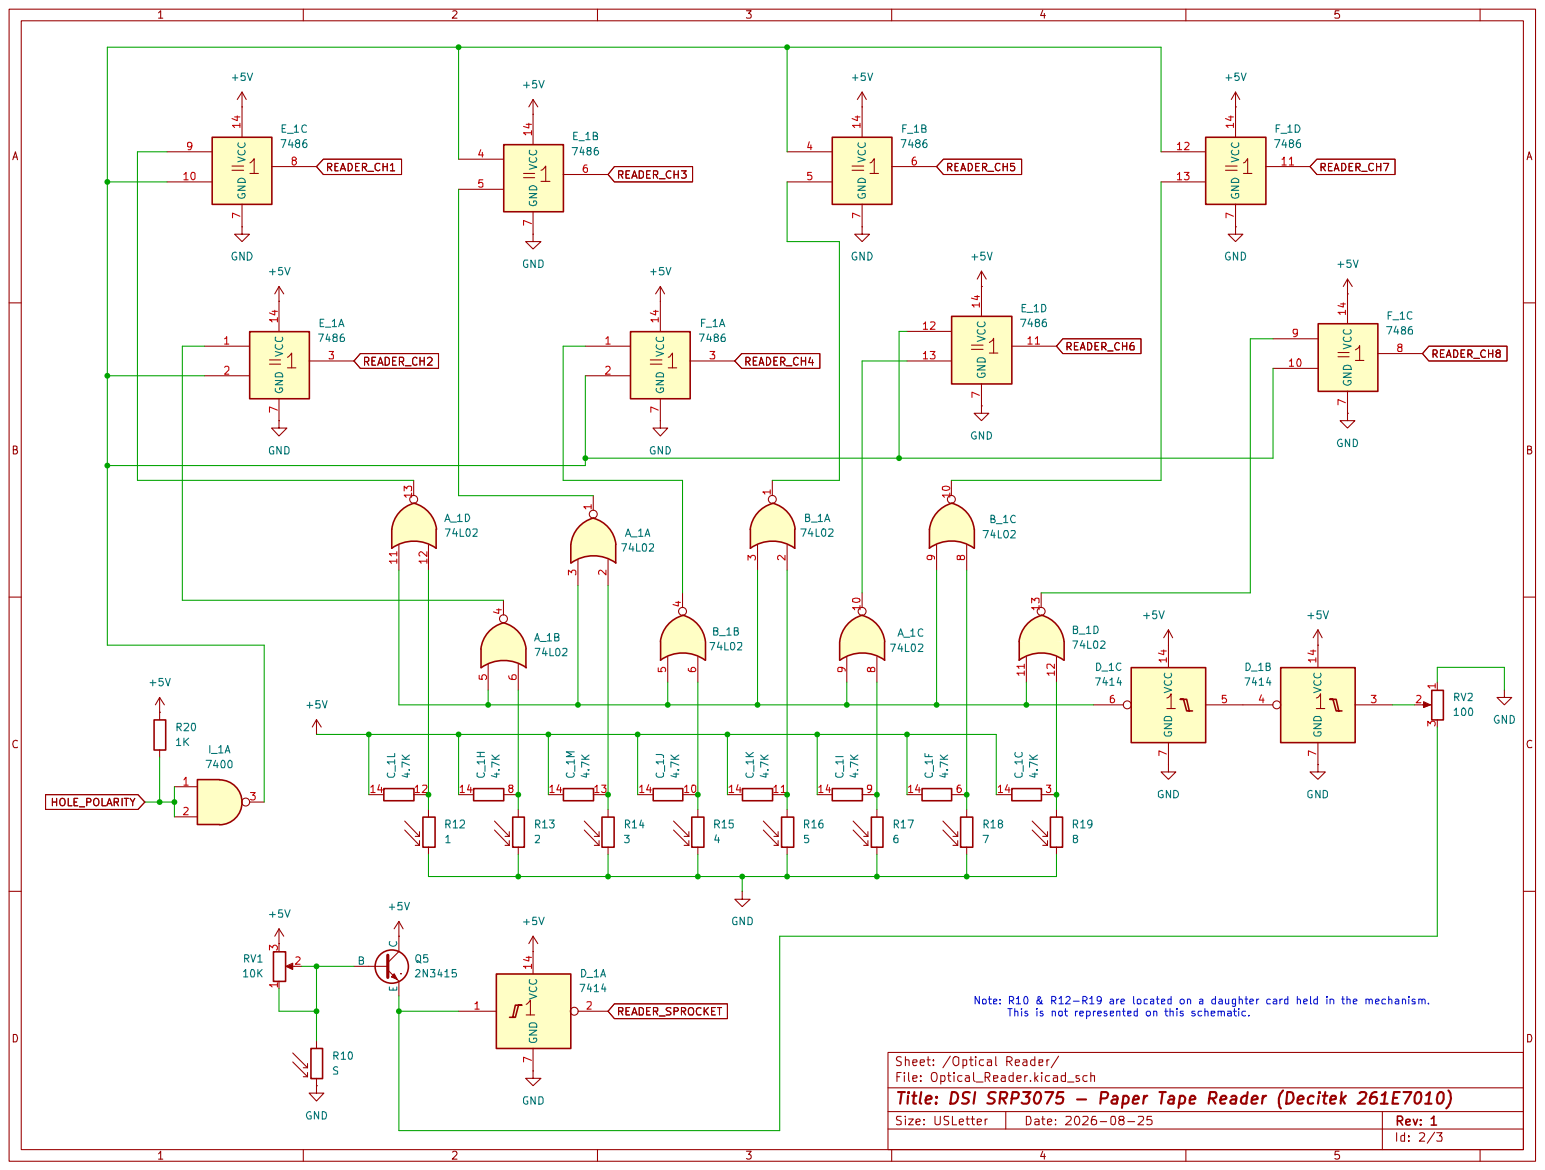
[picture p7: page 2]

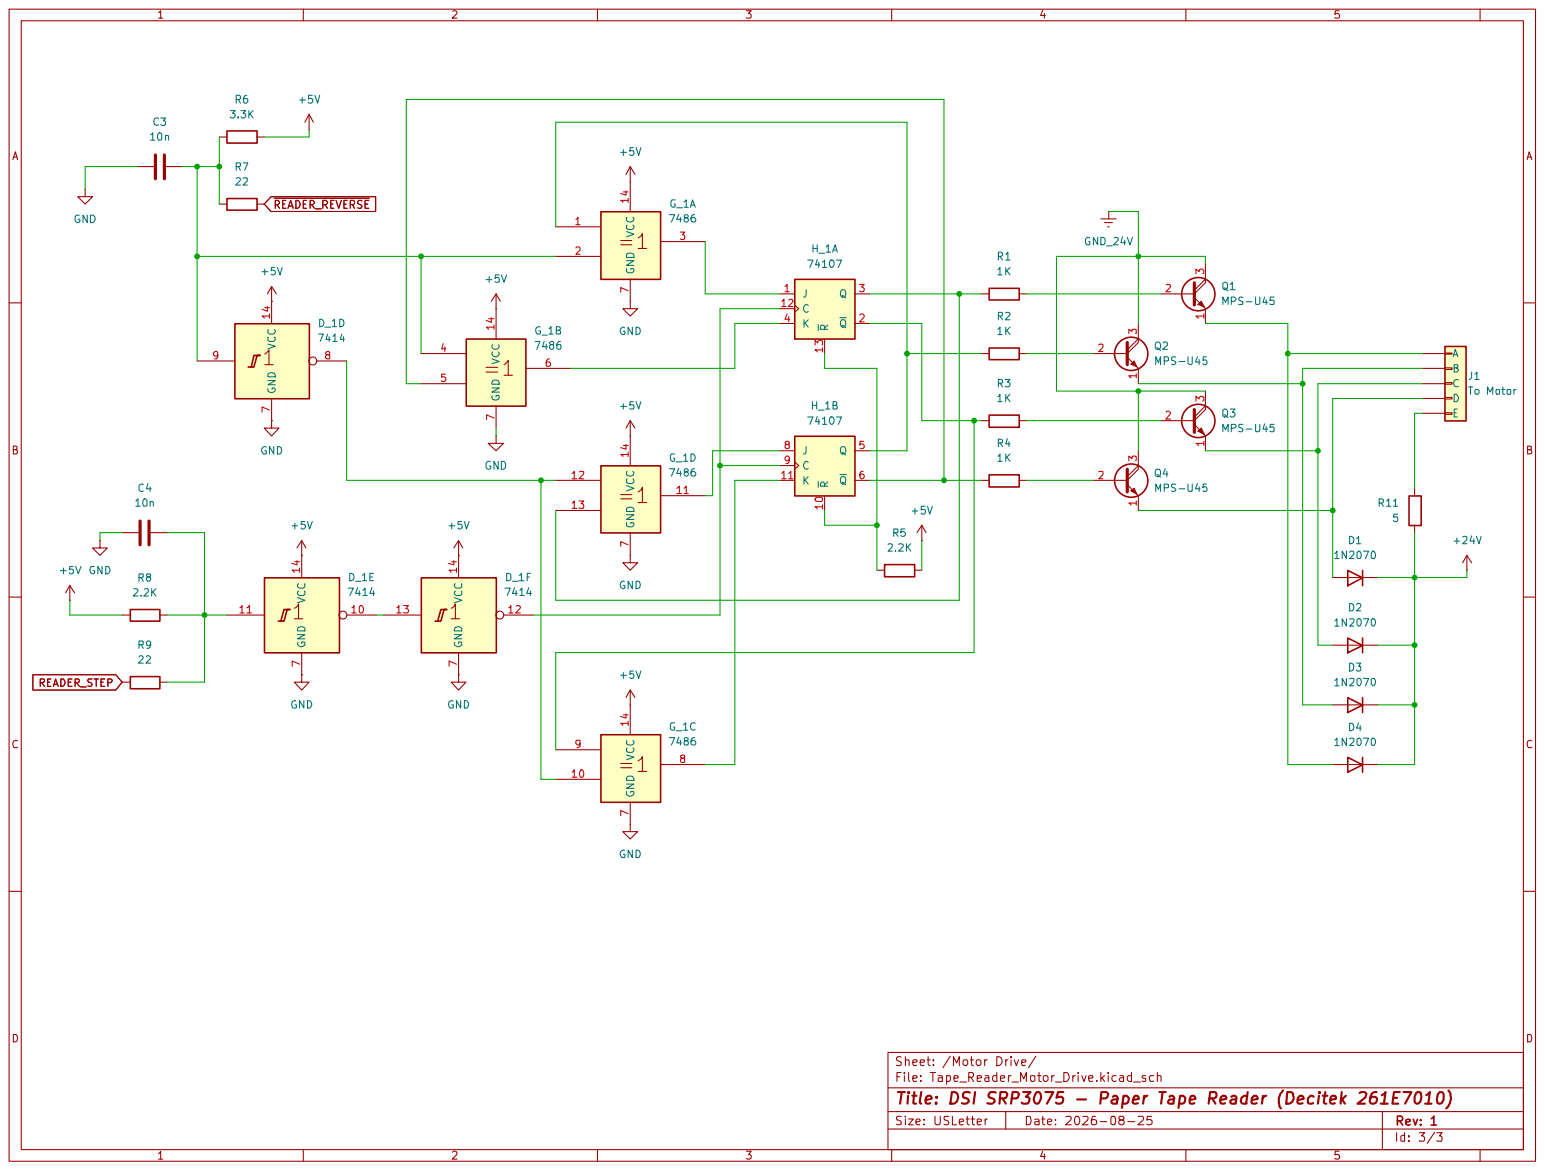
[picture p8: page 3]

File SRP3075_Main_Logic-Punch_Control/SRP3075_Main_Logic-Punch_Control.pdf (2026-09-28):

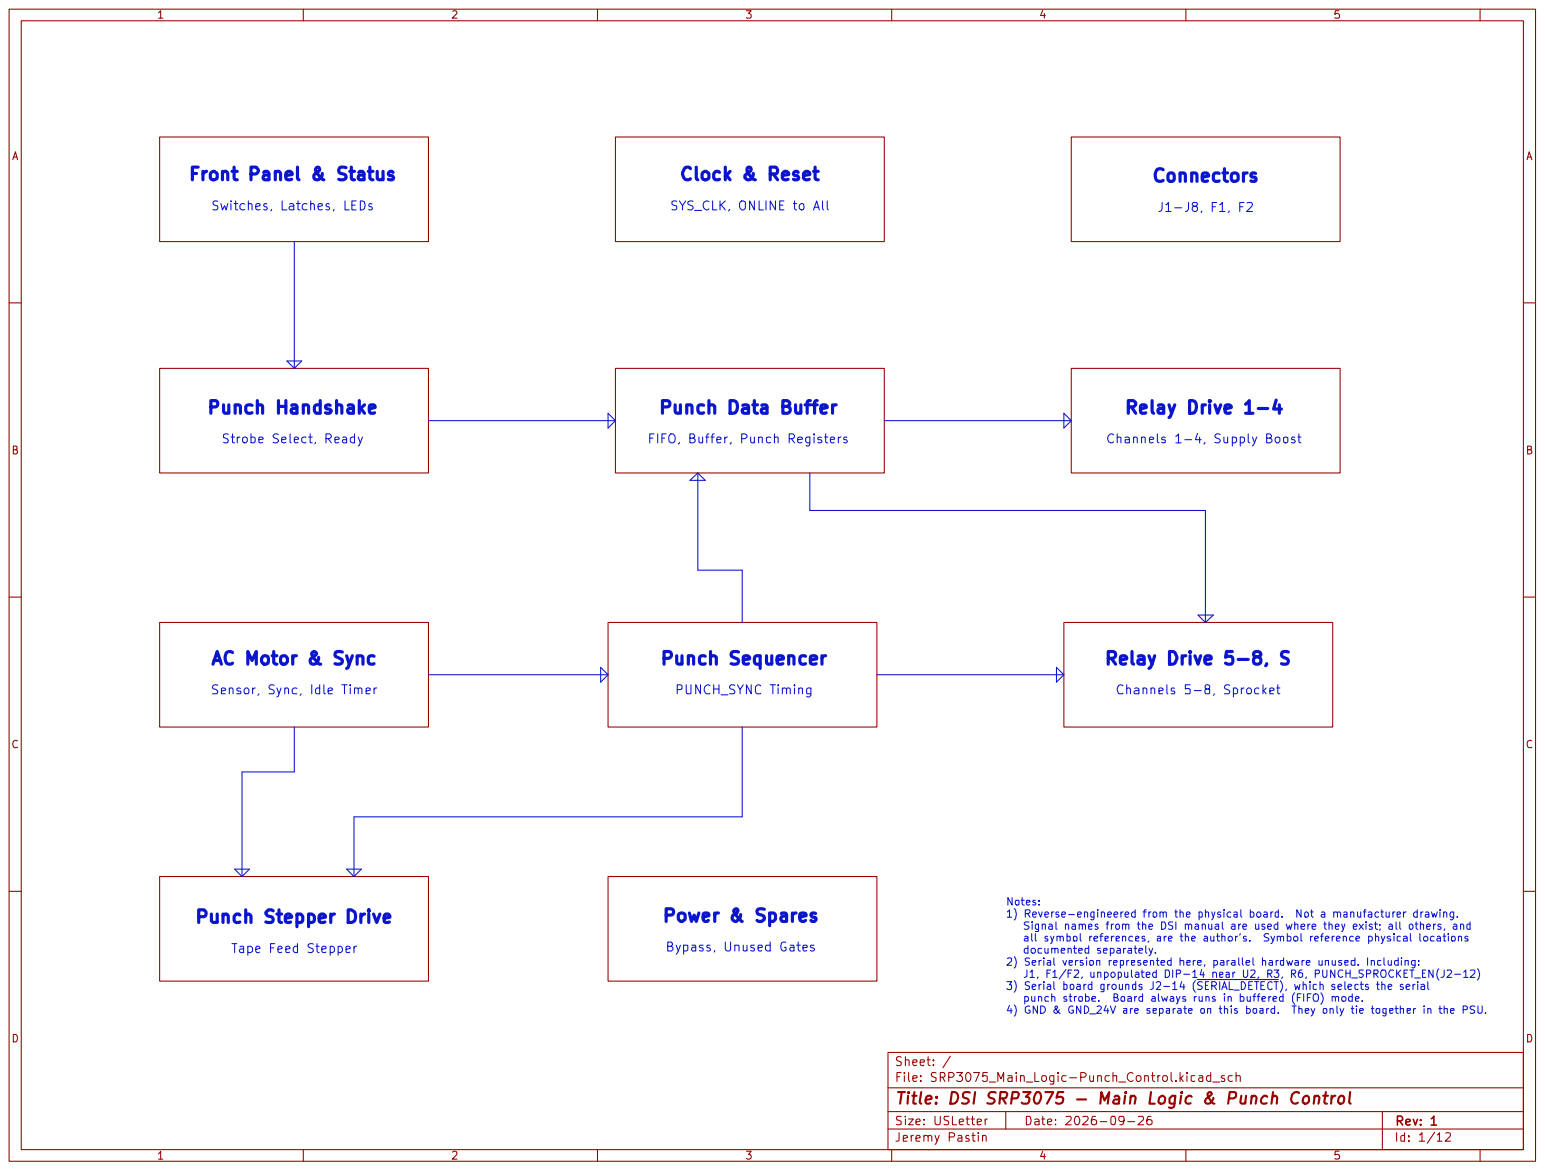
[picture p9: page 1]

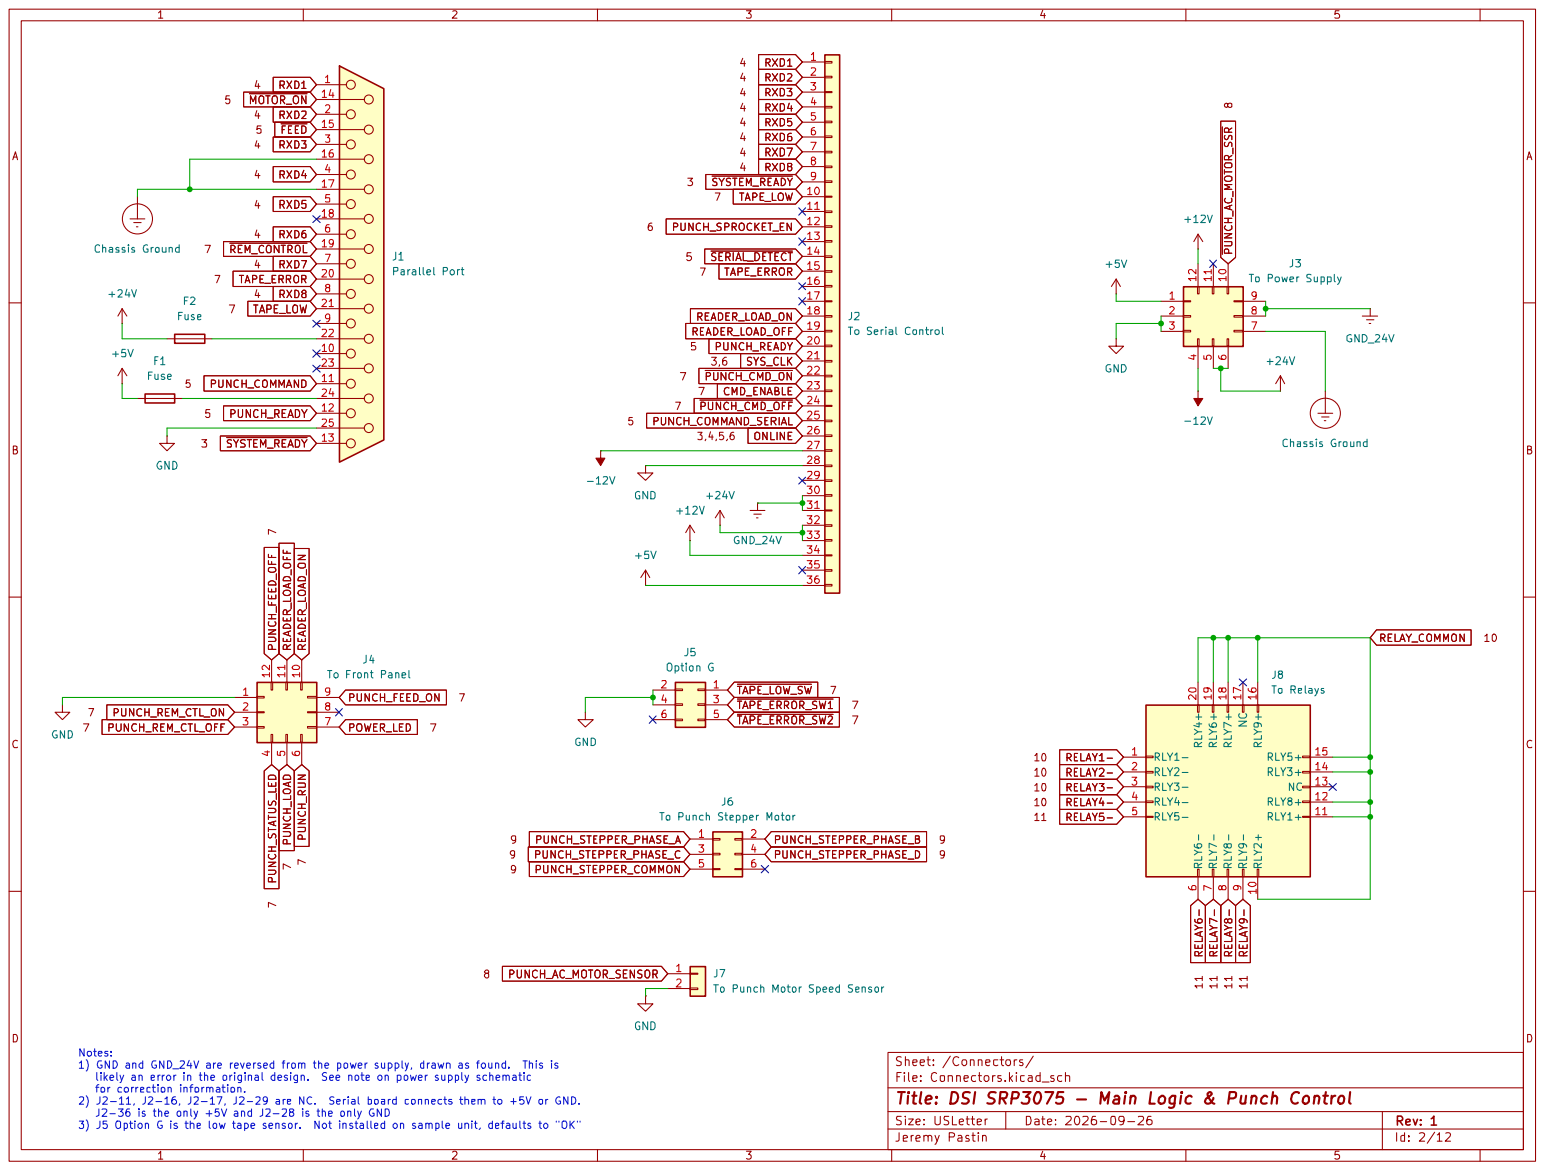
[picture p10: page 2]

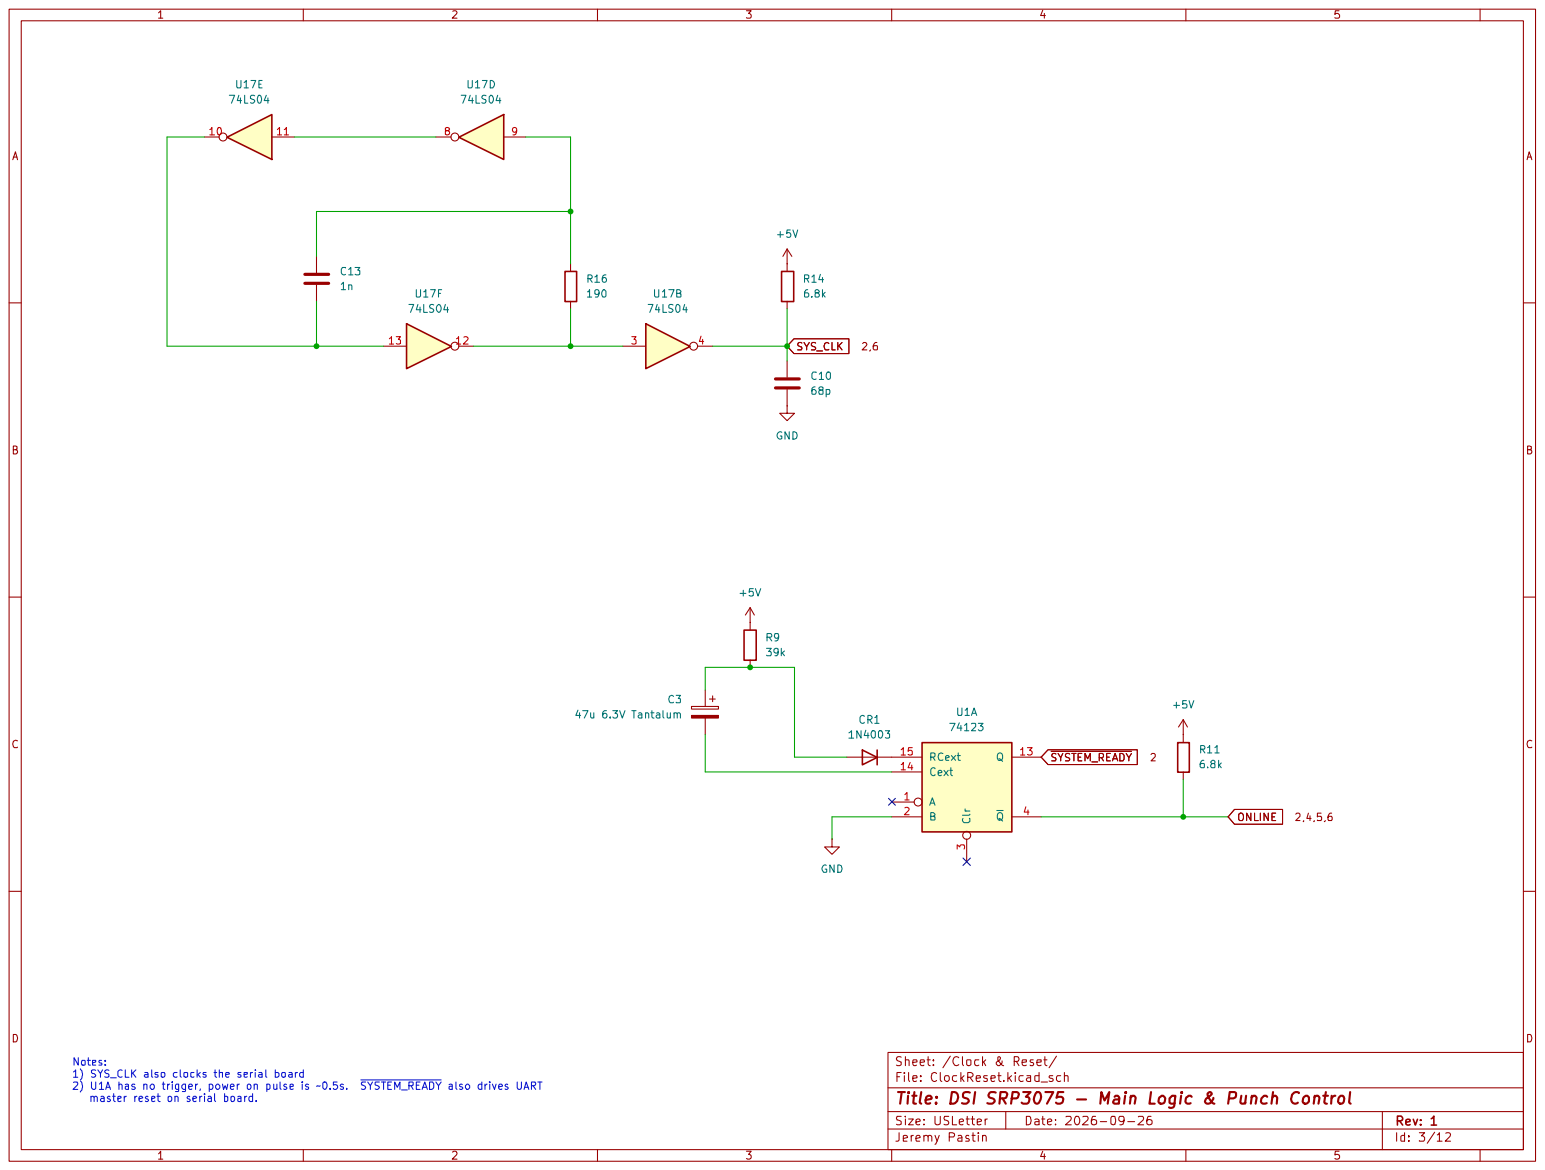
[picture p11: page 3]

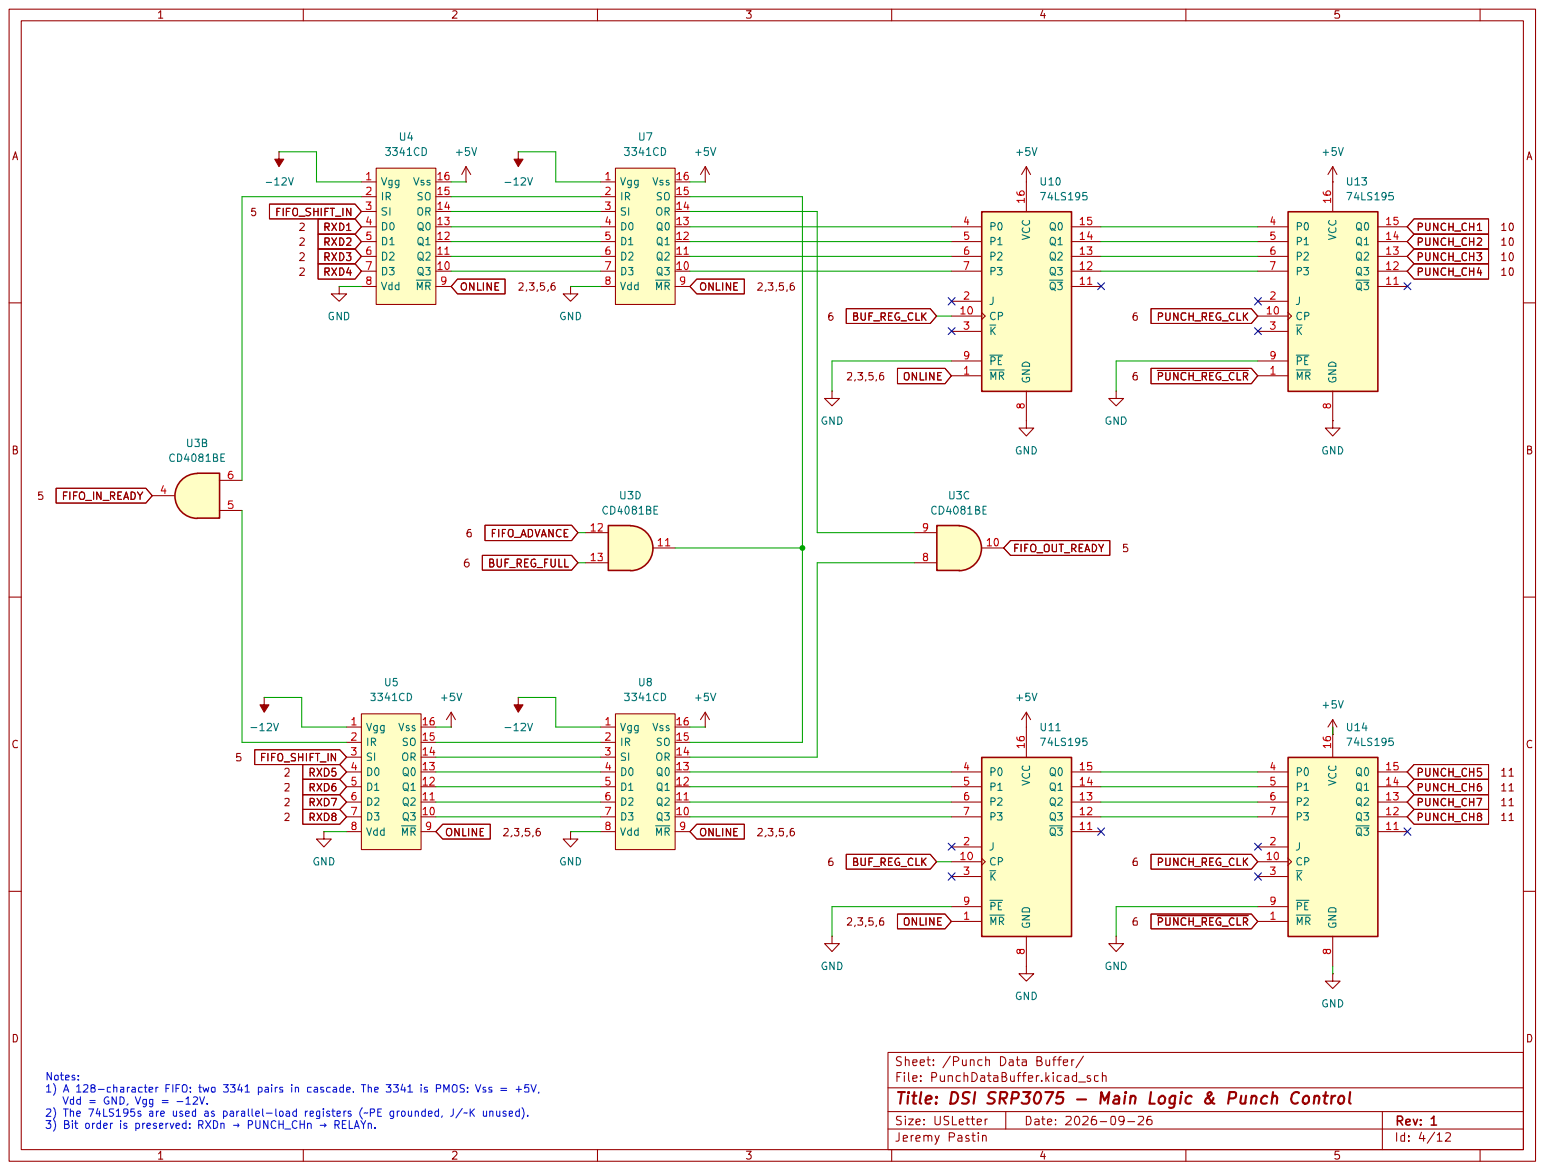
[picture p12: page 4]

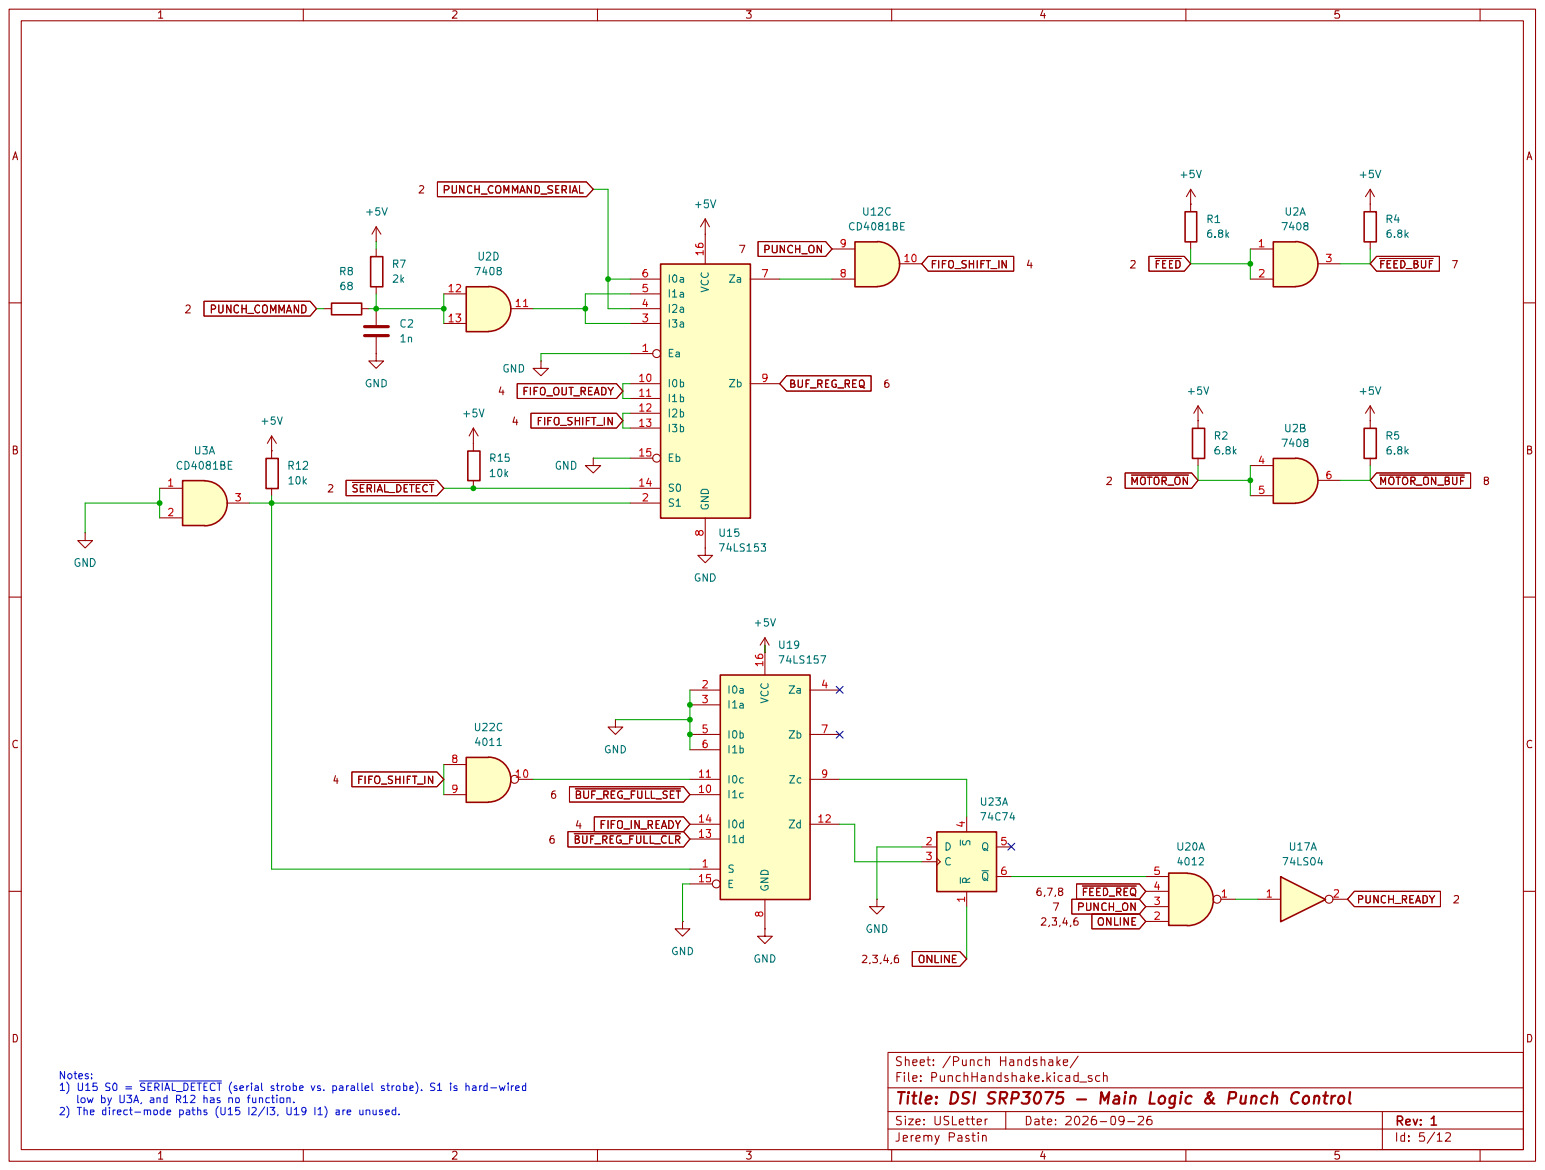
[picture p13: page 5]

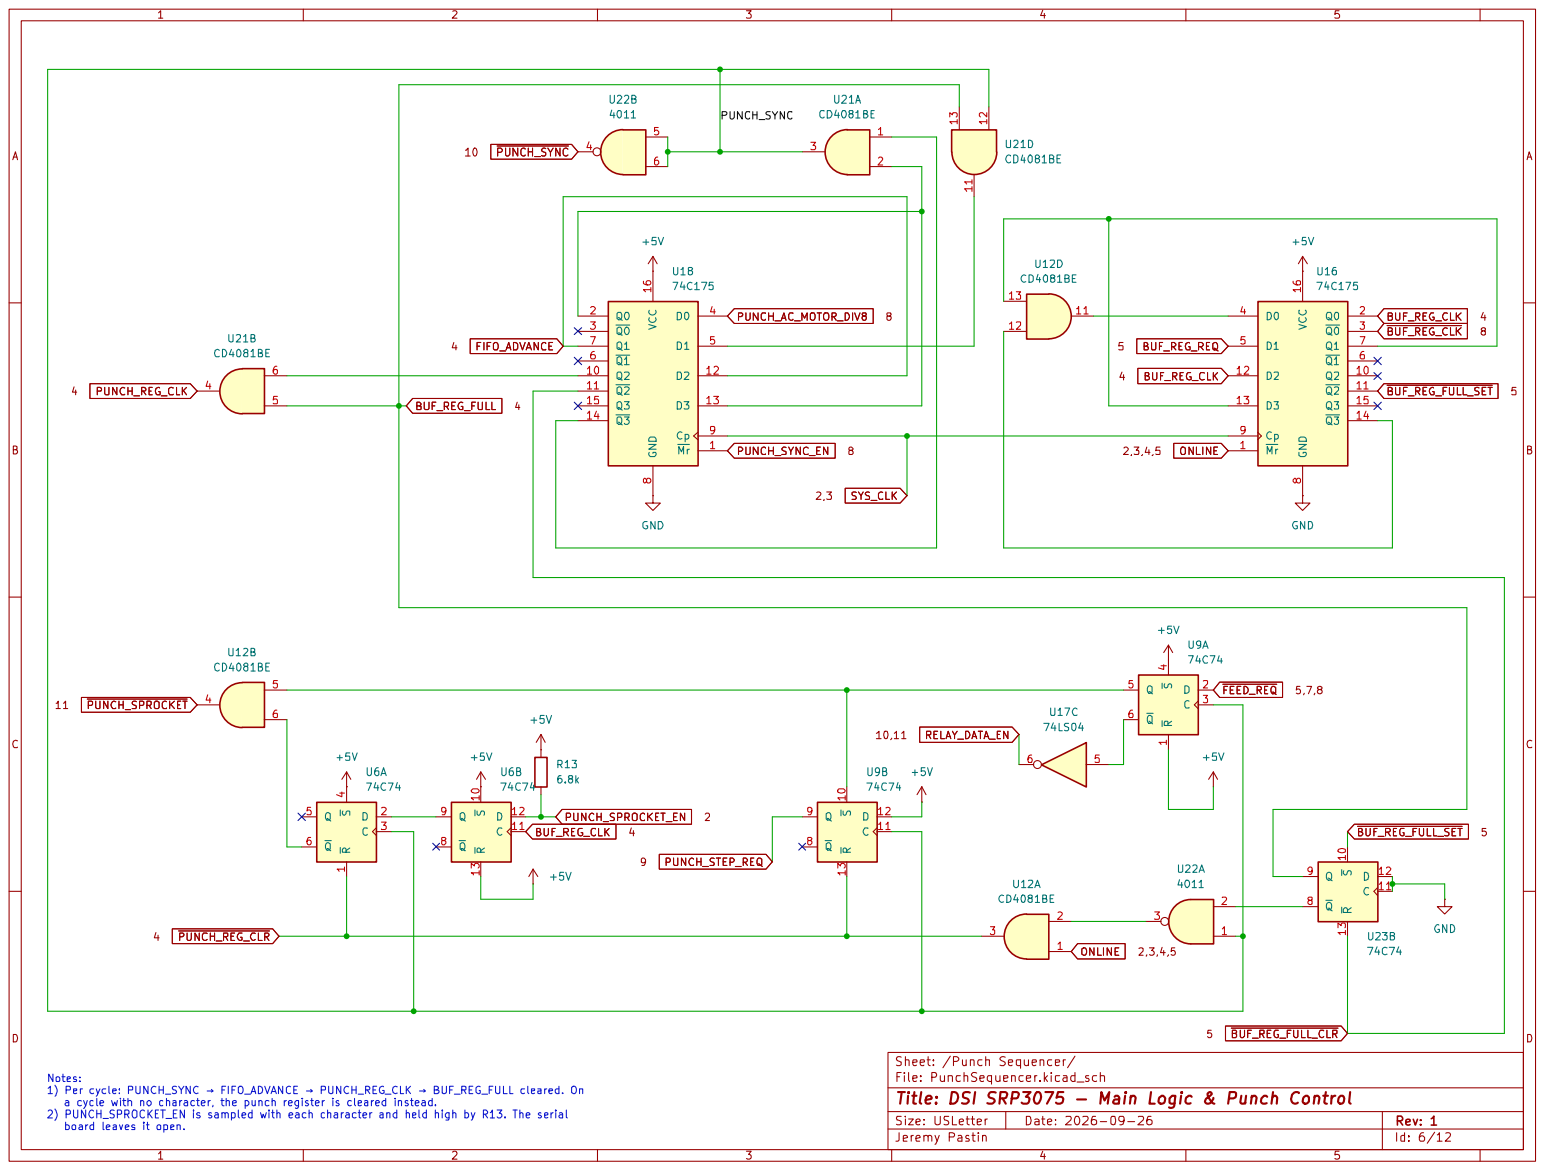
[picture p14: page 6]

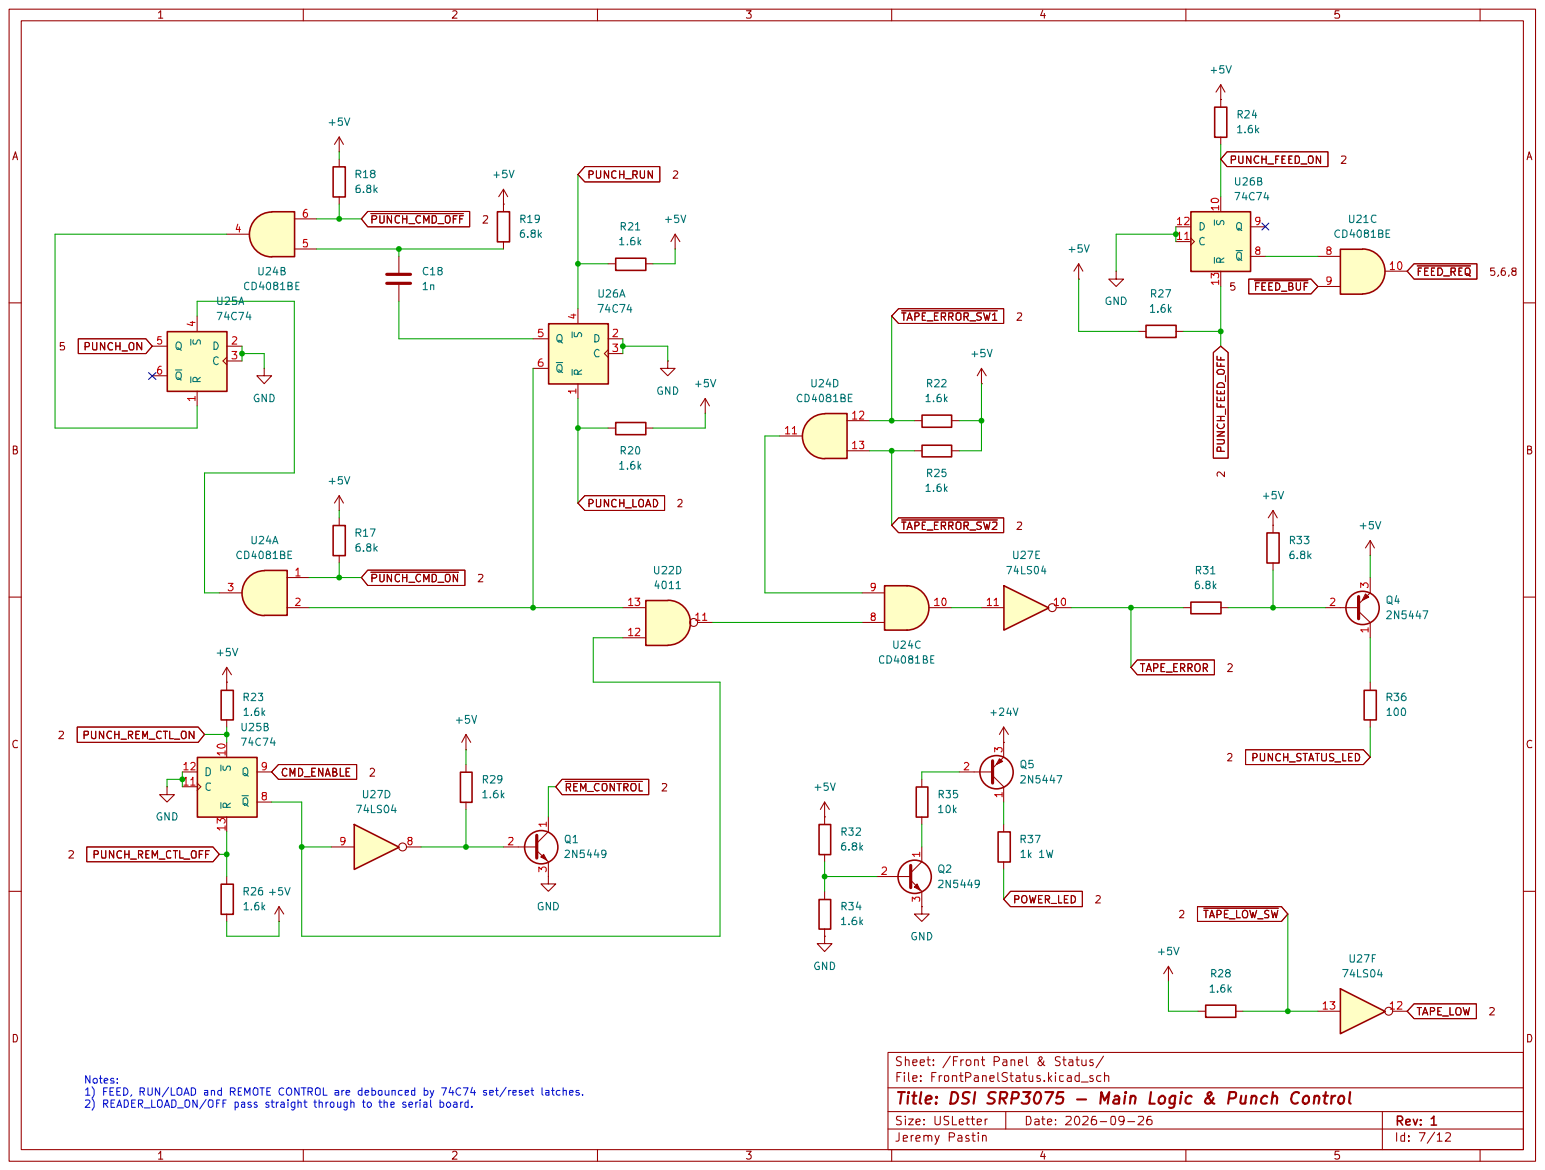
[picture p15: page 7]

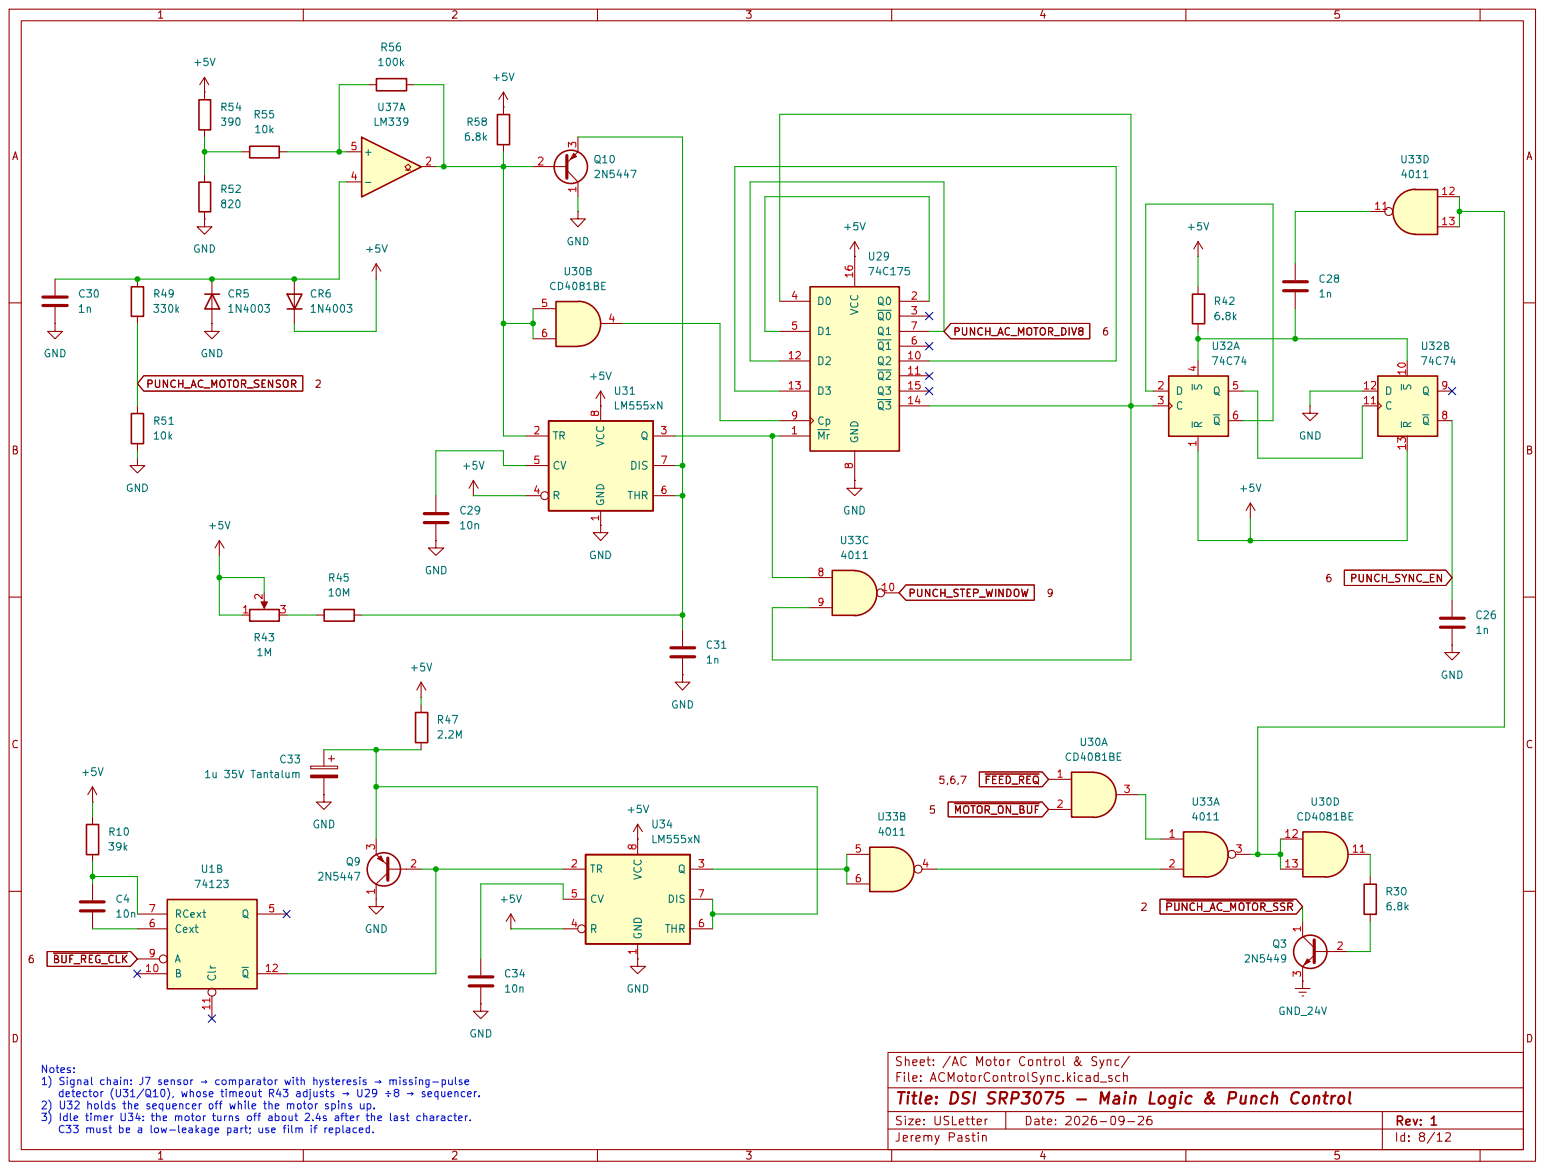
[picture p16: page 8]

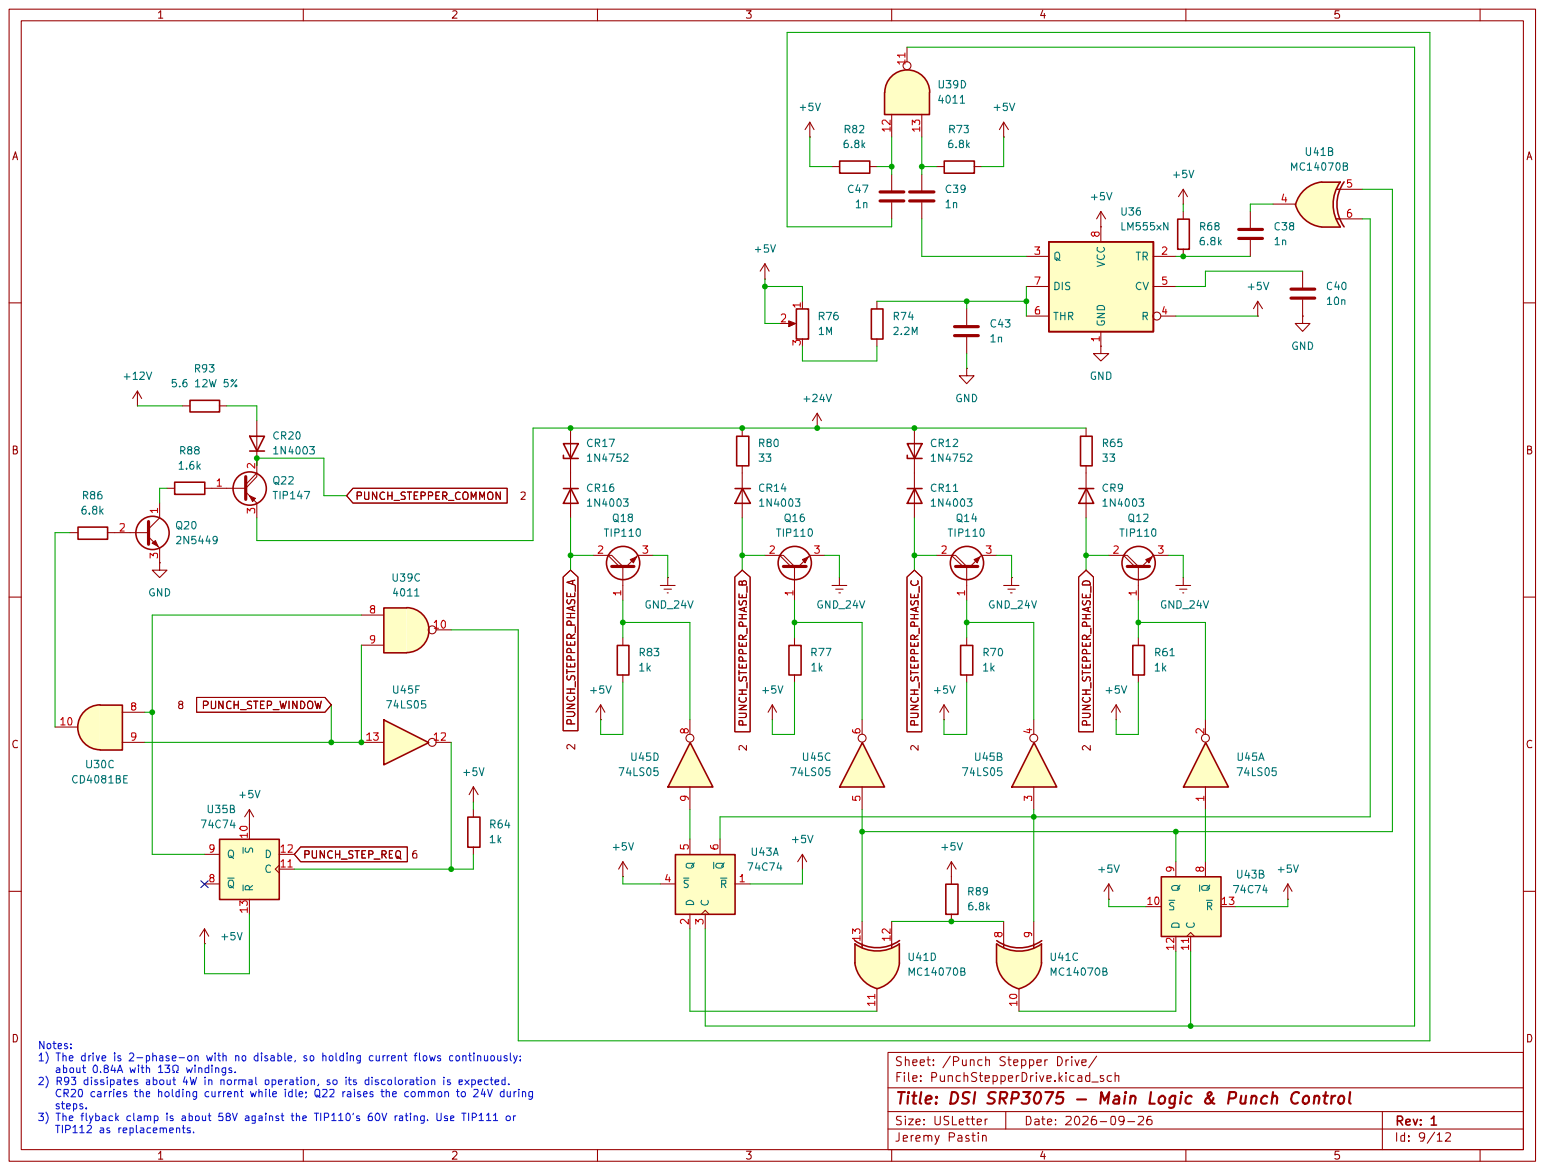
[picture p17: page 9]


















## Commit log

2026-09-28 initial uplaod
    [12V_Rail.kicad_sch, 12V_Rail.kicad_sch.orig.kicad_sch, 24V_Rail.kicad_sch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]
2026-09-29 adding padding on flowchart
2026-10-06 Updated resistor value
    [SRP3075_PowerSupply.kicad_sch]
